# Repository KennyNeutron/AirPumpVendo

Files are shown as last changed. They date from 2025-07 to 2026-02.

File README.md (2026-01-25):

# Coin-Operated Smart Tire Air Pump Vending Machine

## Description

The Coin-Operated Smart Tire Air Pump Vending Machine is a microcontroller-driven, self-service system that provides a fast, safe, and user-friendly way to inflate vehicle tires. Perfect for public locations like vulcanizing shops, parking lots, terminals, and gas stations, it offers tire code lookup, a free DOT safety check, and auto-stop inflation at a target PSI.

## Services

1. **Tire Code Info & Inflation**
   - **Lookup by Code**: Input tire code (e.g., 225/60R16) to get recommended PSI from the internal database.
   - **Manual Input**: Manually set a custom target PSI if the recommended pressure is already known.
   - **Inflation**: Automatic stop at the target PSI with live pressure monitoring.
2. **DOT Code Safety Check (Free Service)**
   - Input DOT code (e.g., 1021) to determine tire age.
   - Displays whether the tire is Safe, requires Caution, or needs Immediate Replacement.

## System Architecture

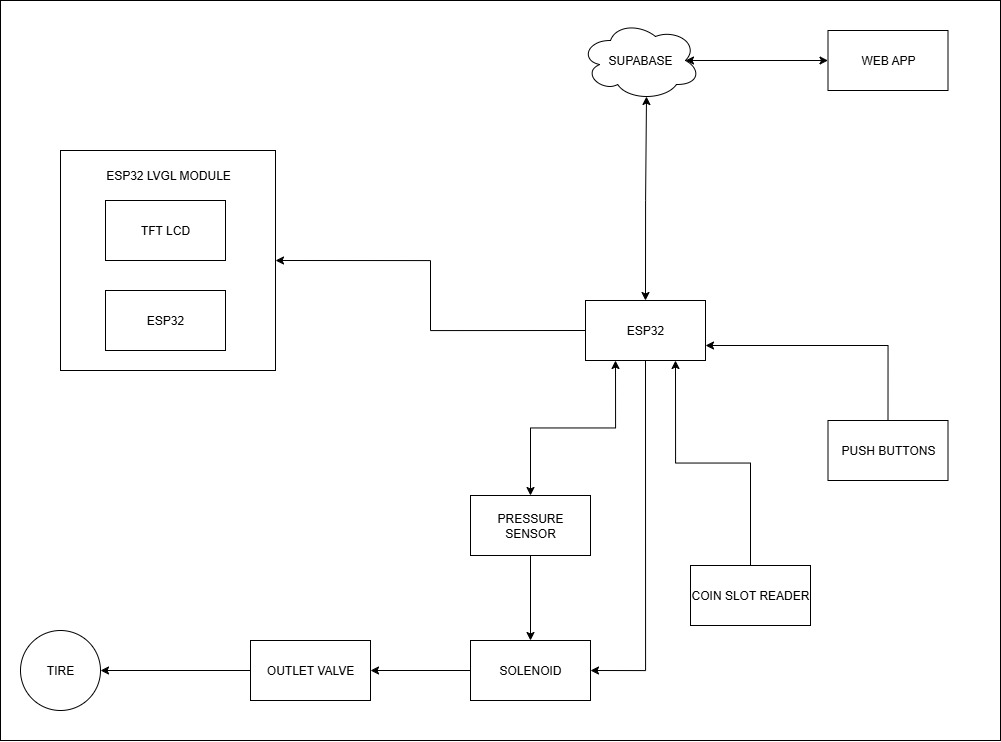
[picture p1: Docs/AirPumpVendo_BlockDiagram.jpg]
Block Diagram


## Hardware Requirements

- Microcontroller (e.g., Arduino Uno or similar)
- TFT display module (7" 800×480 optimized)
- Pressure sensor for live PSI monitoring
- Coin acceptor mechanism (Pulse-based)
- Solid State Relay (SSR) for compressor control
- Power supply and industrial-grade enclosure

## Software Requirements

- **Electron & Next.js**: Modern touch-optimized UI for the operator interface.
- **Arduino Firmware**: C++ logic for sensors, relays, and serial communication.
- **Serial Communication**: Robust protocol between the UI and the controller.

## Installation & Setup

1. **Clone the repository**
   ```bash
   git clone https://github.com/yourusername/smart-tire-air-pump.git
   cd smart-tire-air-pump
   ```
2. **Desktop UI Setup** (Inside `Code/Desktop/AirPumpVendo`)
   ```bash
   npm install
   npm run dev
   ```
3. **Firmware Setup** (Inside `Code/Arduino/AirPumpVendo_Device`)
   - Open `AirPumpVendo_Device.ino` in Arduino IDE.
   - Configure pin definitions and upload to your microcontroller.

## Usage

1. **Select Service**: Choose from the main menu (Tire Service or DOT Check).
2. **Setup Inflation**:
   - For Tire Service: Enter your tire code for a recommendation OR enter PSI manually.
   - For DOT Check: This service is free; follow prompts to check tire safety.
3. **Payment**: Insert coins as required for paid services. The single total cost is displayed on screen.
4. **Inflation**:
   - Connect the hose to the tire valve.
   - Press “Start Inflation.”
   - The machine auto-stops once the target PSI is reached.
5. **Completion**: Remove the hose and return to the home screen.

## Admin Control Panel

- Secure access via password-protected login.
- **Manage Tire Codes**: Add/remove recommended PSI mappings.
- **DOT Database**: Update the list of known DOT codes and safety thresholds.
- **Pricing Management**: Set standard rates for info and inflation services.
- **Analytics**: View weekly revenue reports and service usage statistics.

## Contributing

1. Fork the repository.
2. Create a new branch (`git checkout -b feature/YourFeature`).
3. Commit your changes (`git commit -m "Add YourFeature"`).
4. Push to branch (`git push origin feature/YourFeature`).
5. Open a Pull Request.

## License

This project is licensed under the MIT License. See [LICENSE](LICENSE) for details.

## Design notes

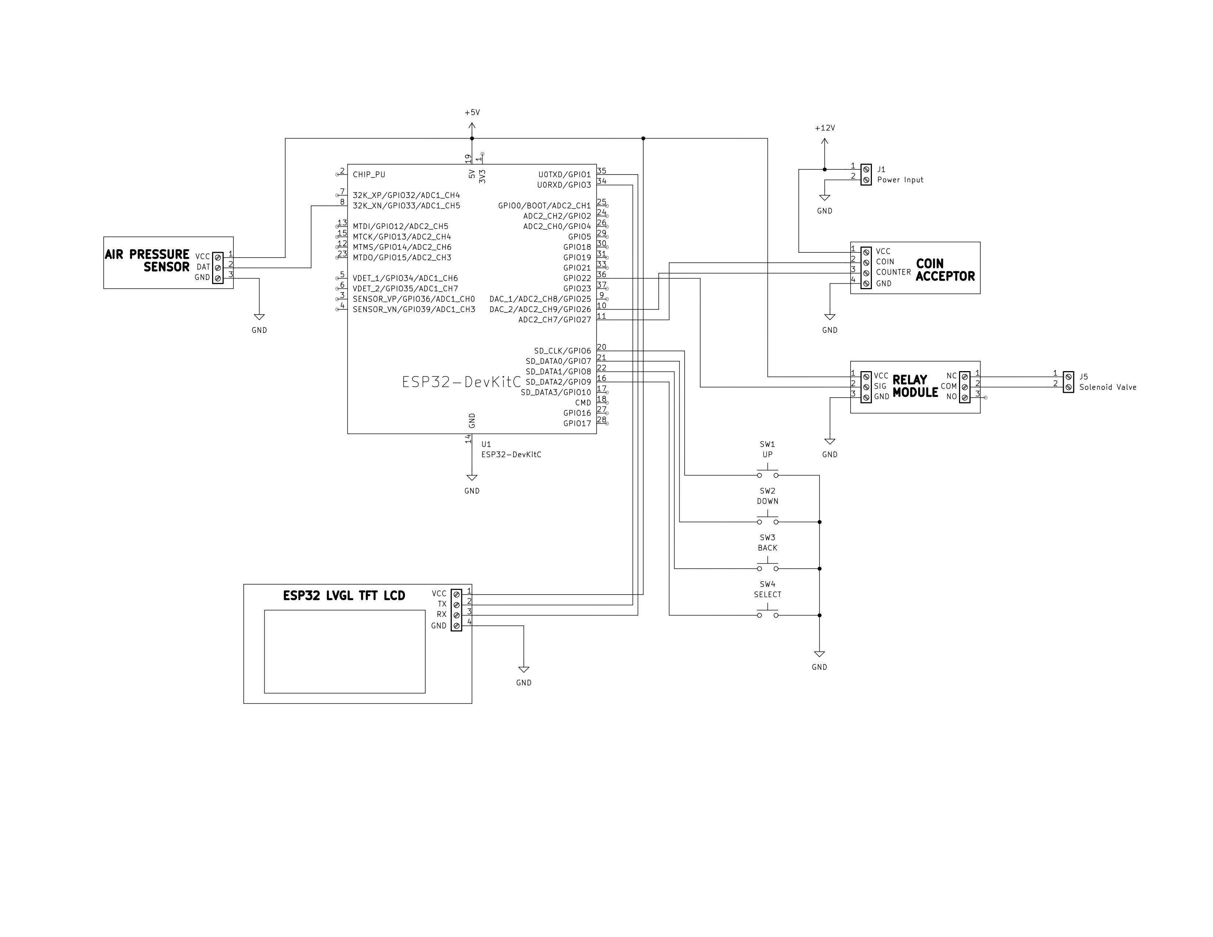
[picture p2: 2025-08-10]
Docs/AirPumpVendo_FullSchematic.jpg

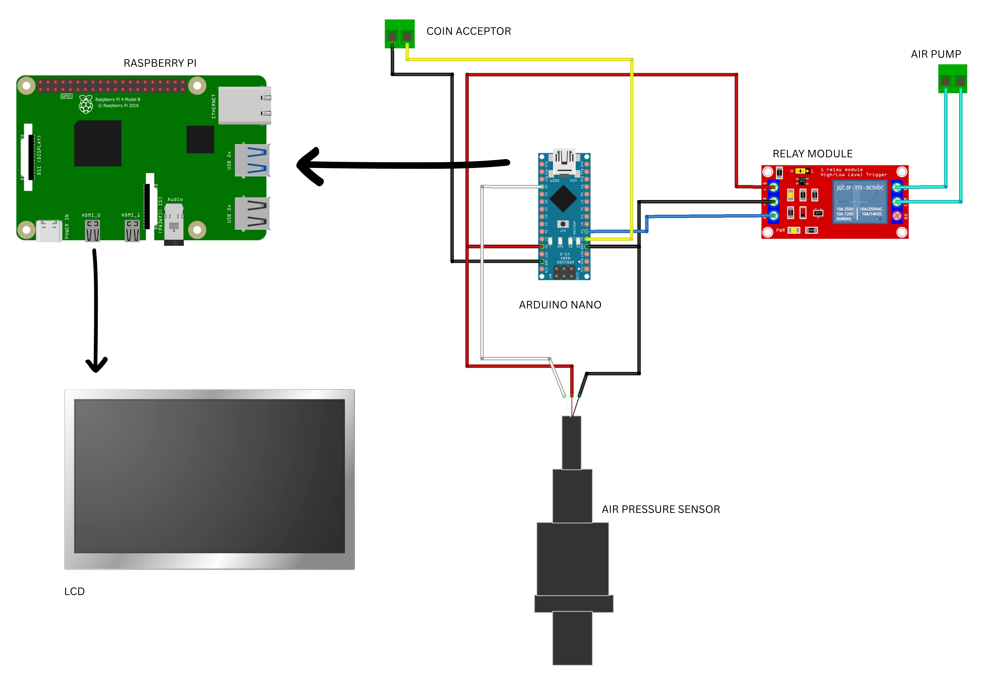
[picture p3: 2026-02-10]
Docs/VendoAirPump_V2.jpg

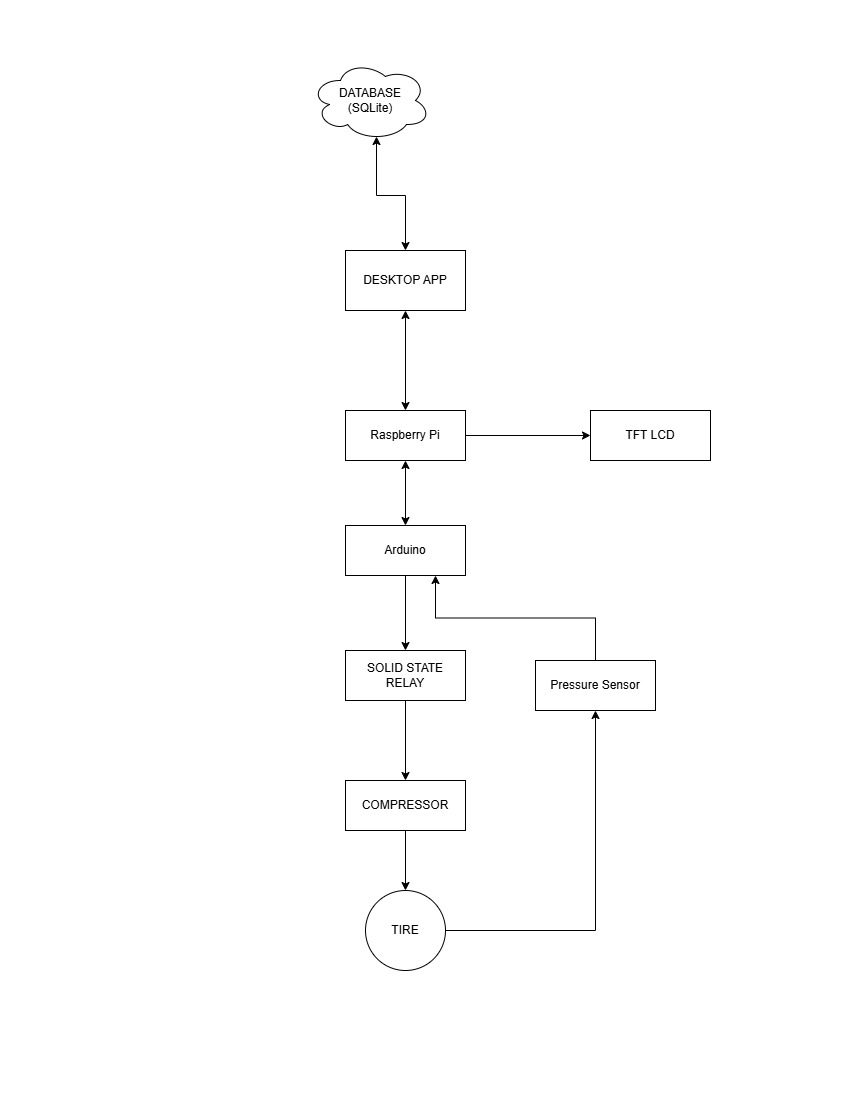
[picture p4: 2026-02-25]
Docs/UpdatedBlockDiagram2026.jpg

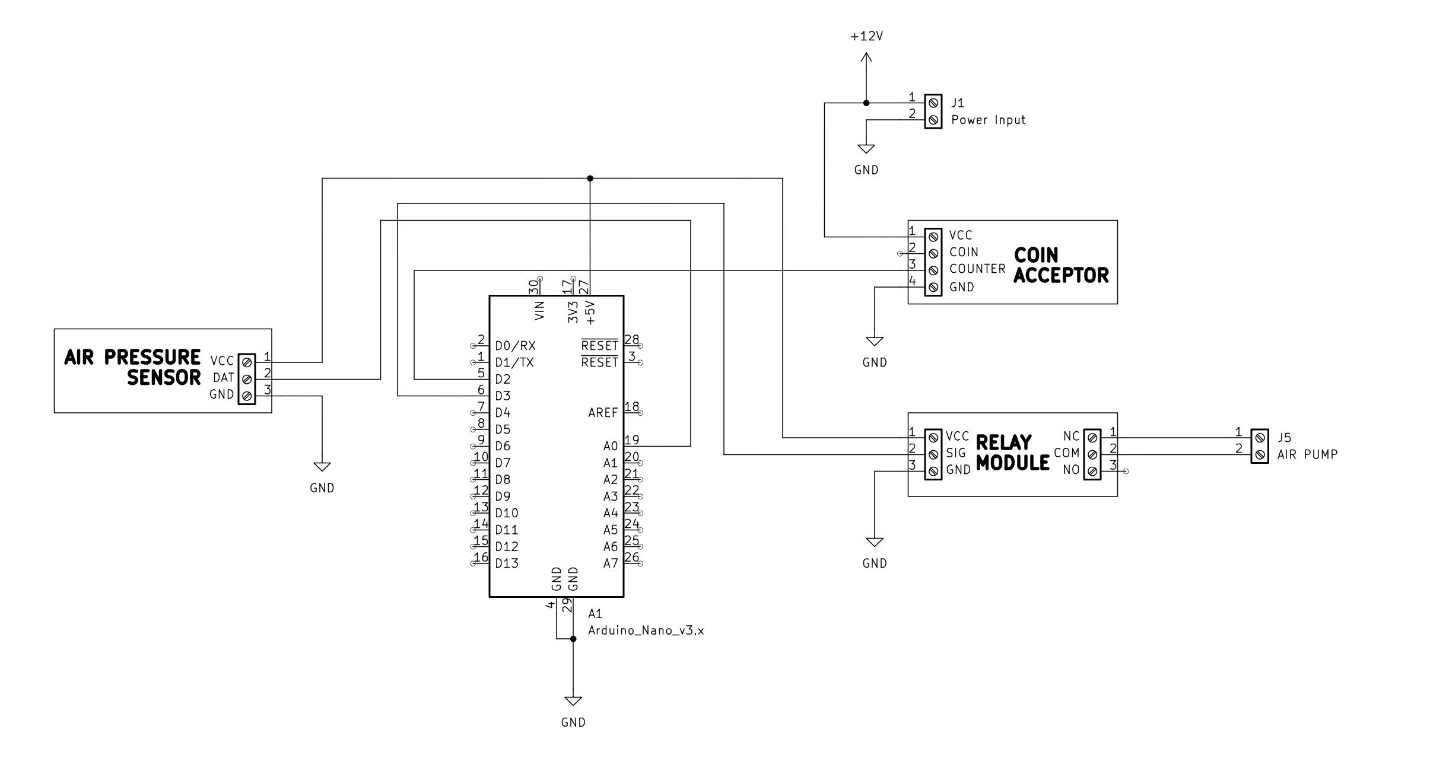
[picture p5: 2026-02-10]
Docs/AirPumpVendo_SCH_V2.jpg

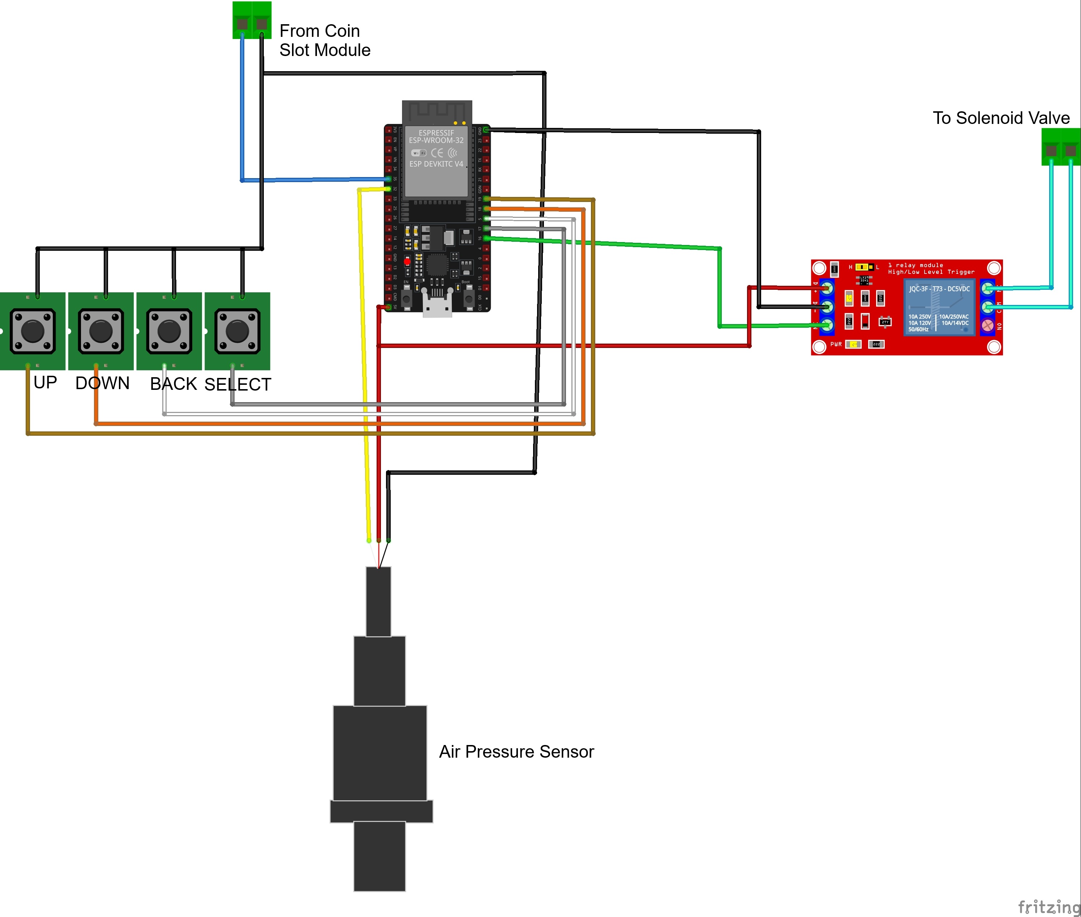
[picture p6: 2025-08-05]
Docs/VendoAirPump_bb.jpg

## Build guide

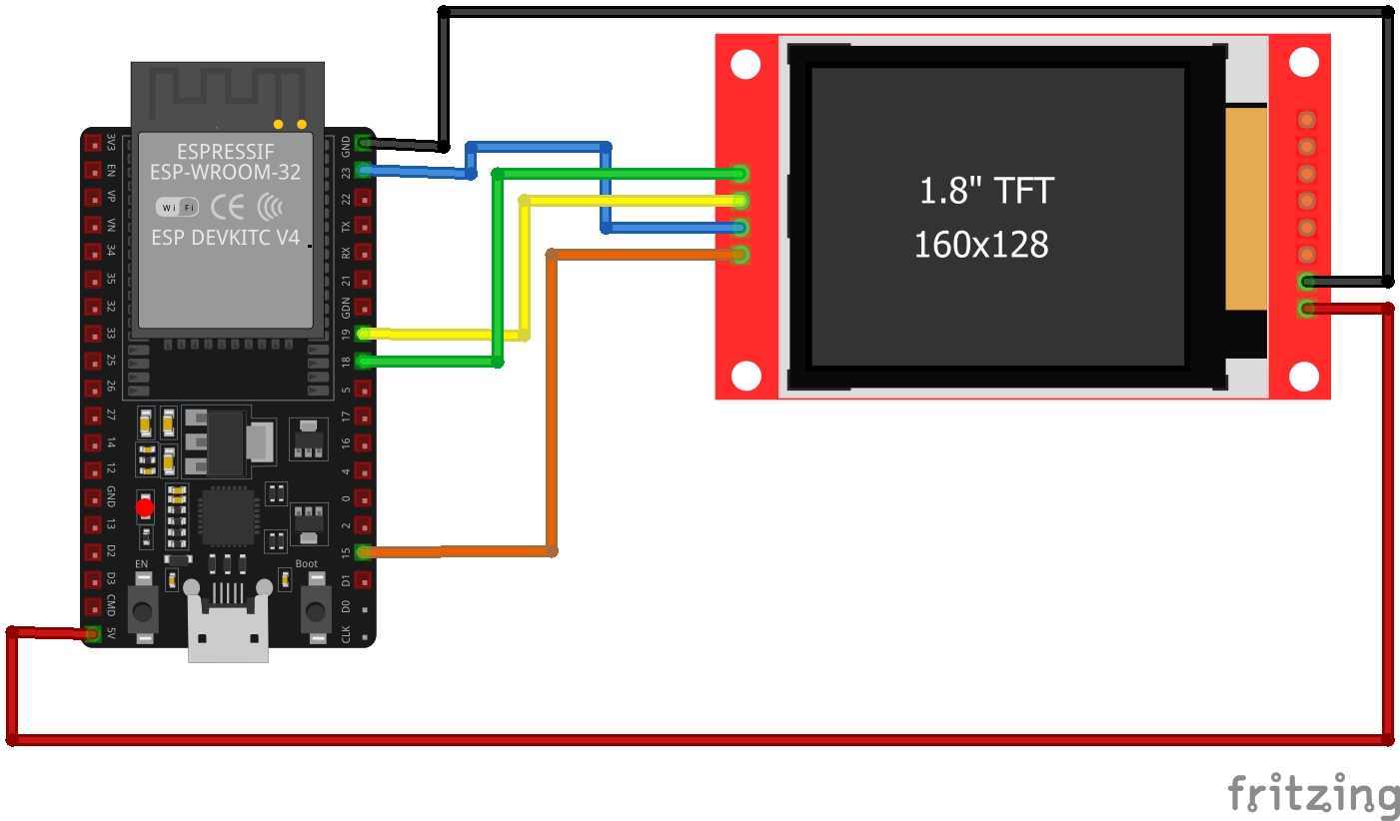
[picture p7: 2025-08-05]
Docs/ESP32_TFT_Module_Wiring.jpg

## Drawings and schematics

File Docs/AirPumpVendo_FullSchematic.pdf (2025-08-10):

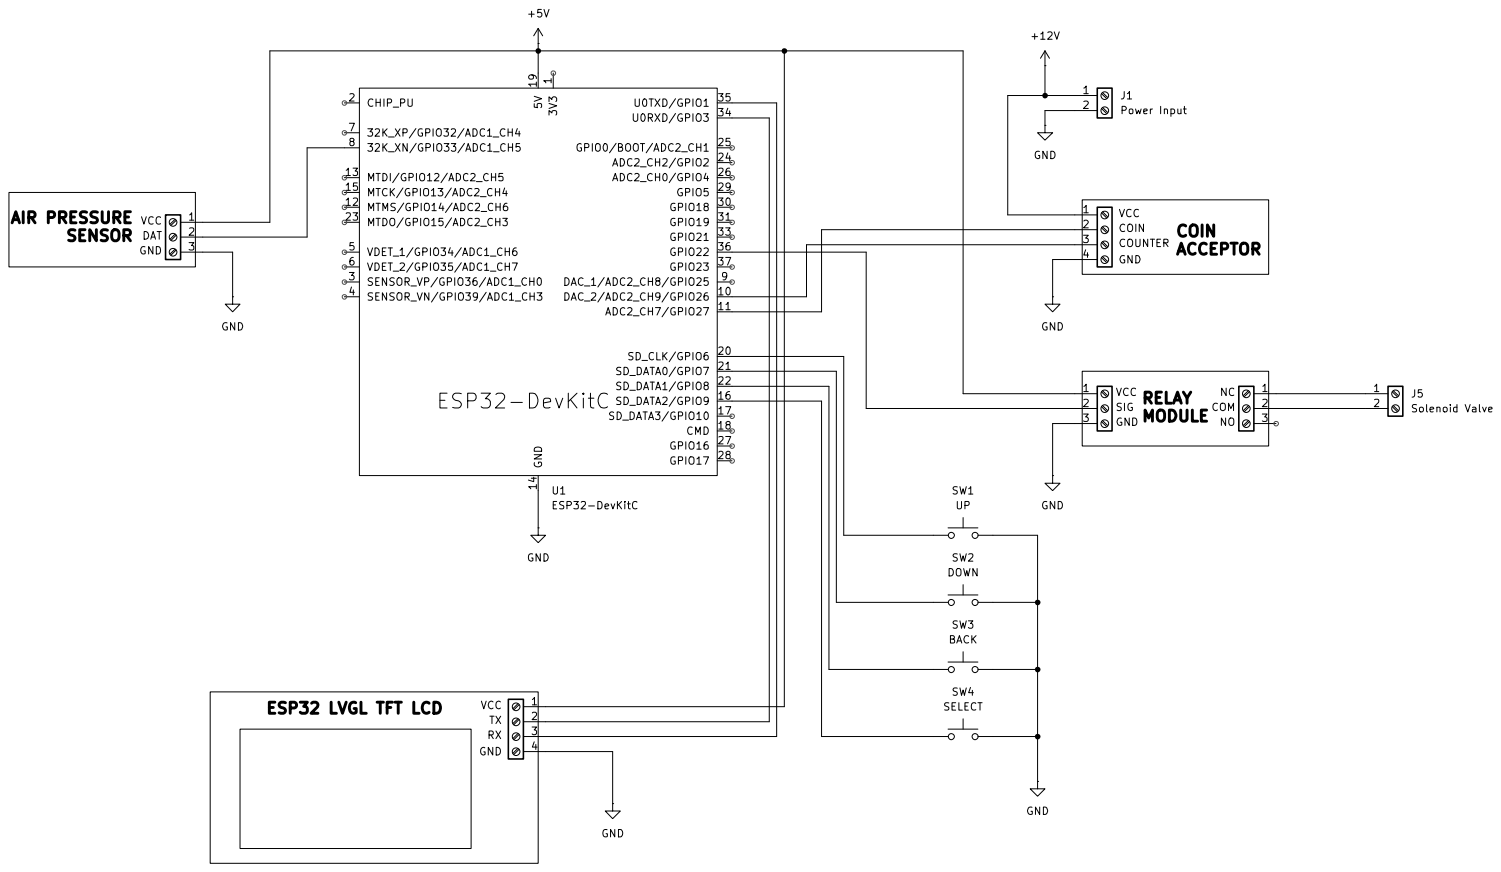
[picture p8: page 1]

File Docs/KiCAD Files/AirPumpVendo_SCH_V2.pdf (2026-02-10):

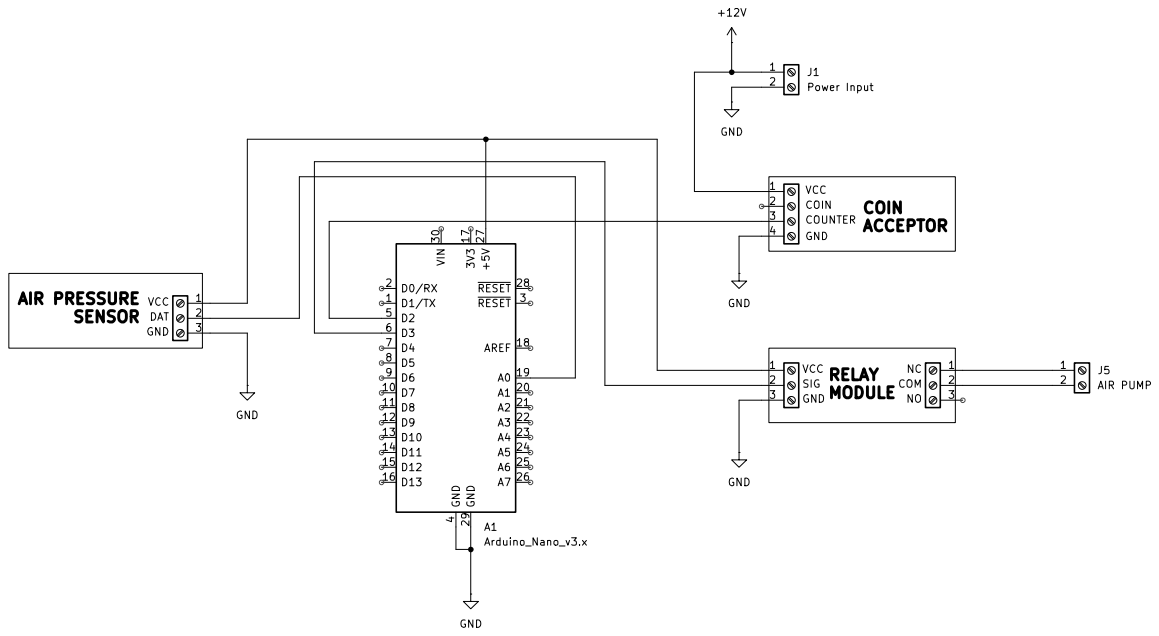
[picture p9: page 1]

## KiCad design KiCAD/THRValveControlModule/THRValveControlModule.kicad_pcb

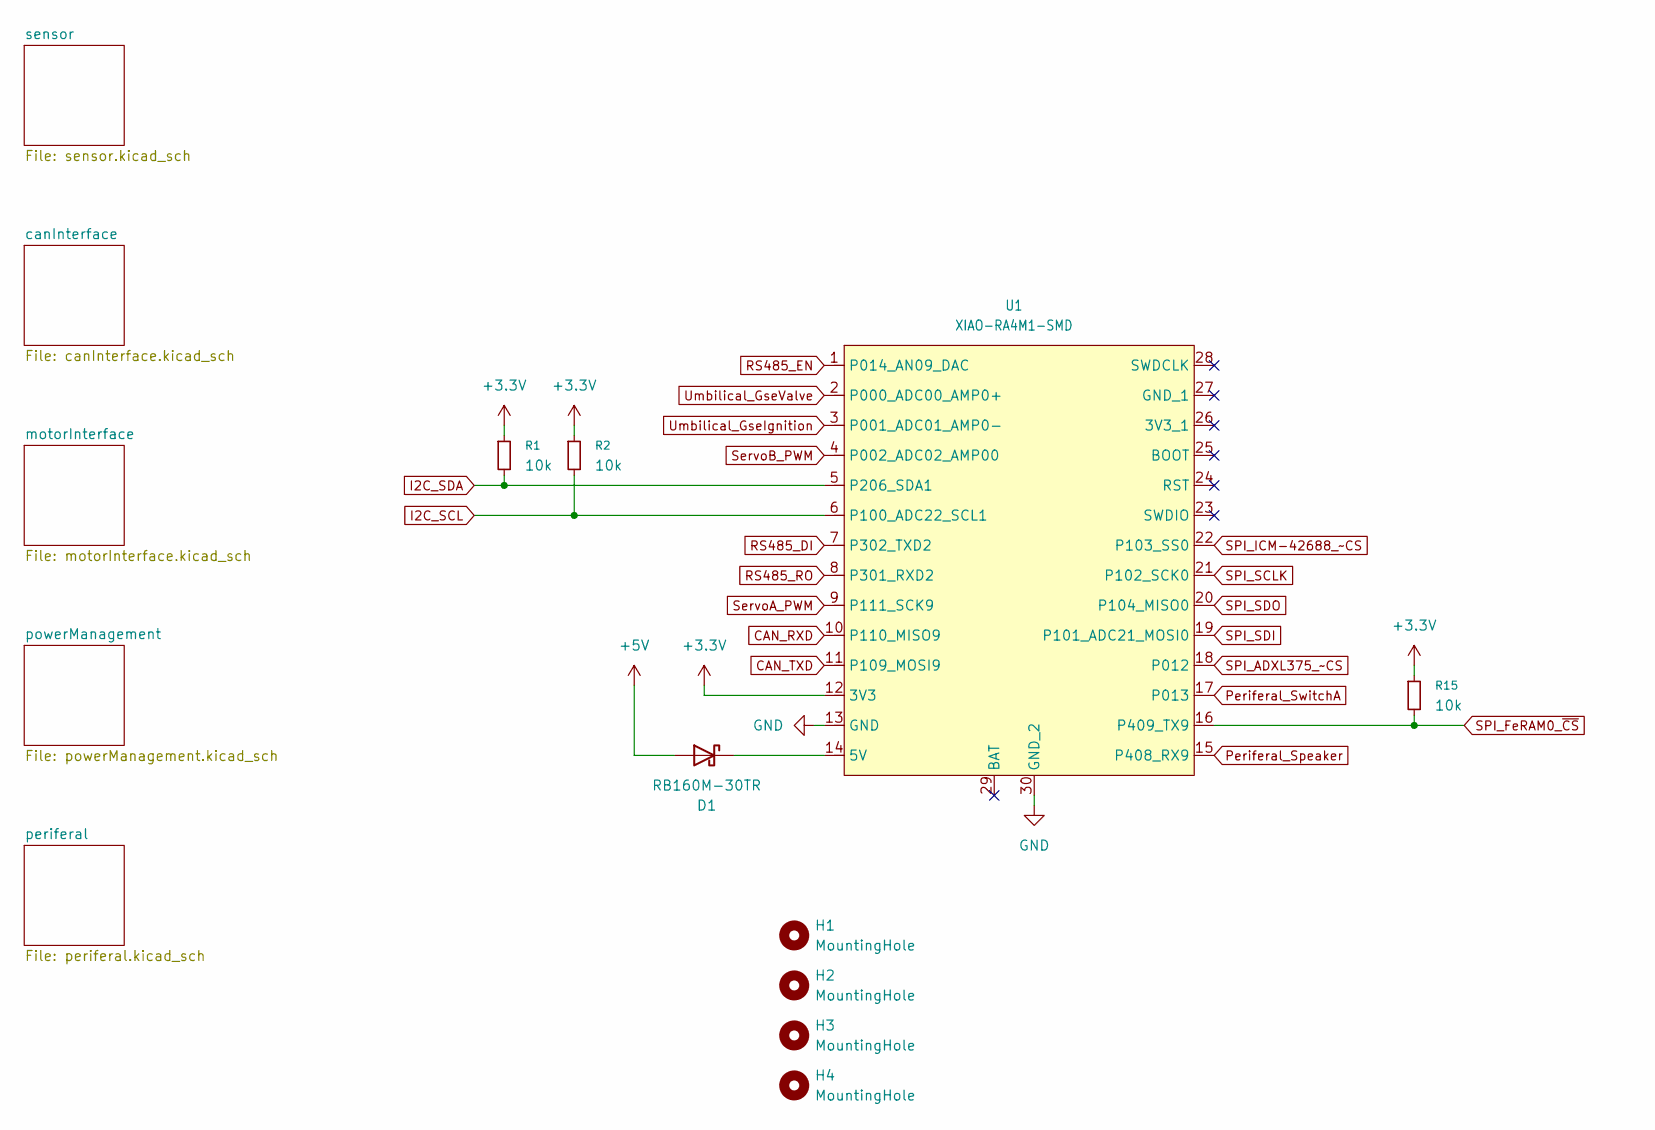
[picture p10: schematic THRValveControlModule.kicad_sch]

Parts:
D1: RB160M-30TR; D_SOD-123
H1, H2, H3, H4: MountingHole; MountingHole_3.2mm_M3_Pad_Via
R1, R2, R15: 10k; R_0603_1608Metric_Pad0.98x0.95mm_HandSolder
U1: XIAO-RA4M1-SMD

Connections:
+3.3V: R1.1, R2.1, R15.1, U1.12 (3V3); also elsewhere on the board
+5V: D1.2 (A); also elsewhere on the board
CAN_RXD: U1.10 (P110_MISO9); also elsewhere on the board
CAN_TXD: U1.11 (P109_MOSI9); also elsewhere on the board
GND: U1.13 (GND), U1.30 (GND_2); also elsewhere on the board
I2C_SCL: R2.2, U1.6 (P100_ADC22_SCL1); also elsewhere on the board
I2C_SDA: R1.2, U1.5 (P206_SDA1); also elsewhere on the board
unnamed: D1.1 (K), U1.14 (5V)
Periferal_Speaker: U1.15 (P408_RX9); also elsewhere on the board
Periferal_SwitchA: U1.17 (P013); also elsewhere on the board
RS485_DI: U1.7 (P302_TXD2); also elsewhere on the board
RS485_EN: U1.1 (P014_AN09_DAC); also elsewhere on the board
RS485_RO: U1.8 (P301_RXD2); also elsewhere on the board
SPI_ADXL375_~CS: U1.18 (P012); also elsewhere on the board
SPI_FeRAM0_~CS: R15.2, U1.16 (P409_TX9); also elsewhere on the board
SPI_ICM-42688_~CS: U1.22 (P103_SS0); also elsewhere on the board
SPI_SCLK: U1.21 (P102_SCK0); also elsewhere on the board
SPI_SDI: U1.19 (P101_ADC21_MOSI0); also elsewhere on the board
SPI_SDO: U1.20 (P104_MISO0); also elsewhere on the board
ServoA_PWM: U1.9 (P111_SCK9); also elsewhere on the board
ServoB_PWM: U1.4 (P002_ADC02_AMP00); also elsewhere on the board
Umbilical_GseIgnition: U1.3 (P001_ADC01_AMP0-); also elsewhere on the board
Umbilical_GseValve: U1.2 (P000_ADC00_AMP0+); also elsewhere on the board

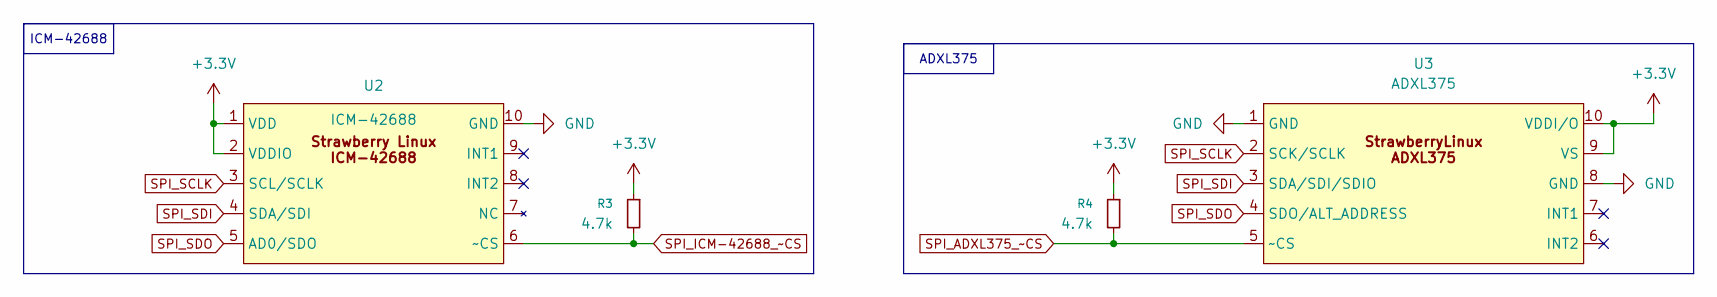
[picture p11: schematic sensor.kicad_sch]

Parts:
R3, R4: 4.7k; R_0603_1608Metric_Pad0.98x0.95mm_HandSolder
U2: ICM-42688; StrawberryLinux_ICM-42688-P
U3: ADXL375; StrawberryLinux_ADXL375

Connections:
+3.3V: R3.1, R4.1, U2.1 (VDD), U2.2 (VDDIO), U3.9 (VS), U3.10 (VDDI/O); also elsewhere on the board
GND: U2.10 (GND), U3.1 (GND), U3.8 (GND); also elsewhere on the board
SPI_ADXL375_~CS: R4.2, U3.5 (~CS); also elsewhere on the board
SPI_ICM-42688_~CS: R3.2, U2.6 (~CS); also elsewhere on the board
SPI_SCLK: U2.3 (SCL/SCLK), U3.2 (SCK/SCLK); also elsewhere on the board
SPI_SDI: U2.4 (SDA/SDI), U3.3 (SDA/SDI/SDIO); also elsewhere on the board
SPI_SDO: U2.5 (AD0/SDO), U3.4 (SDO/ALT_ADDRESS); also elsewhere on the board

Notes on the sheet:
ICM-42688
ADXL375

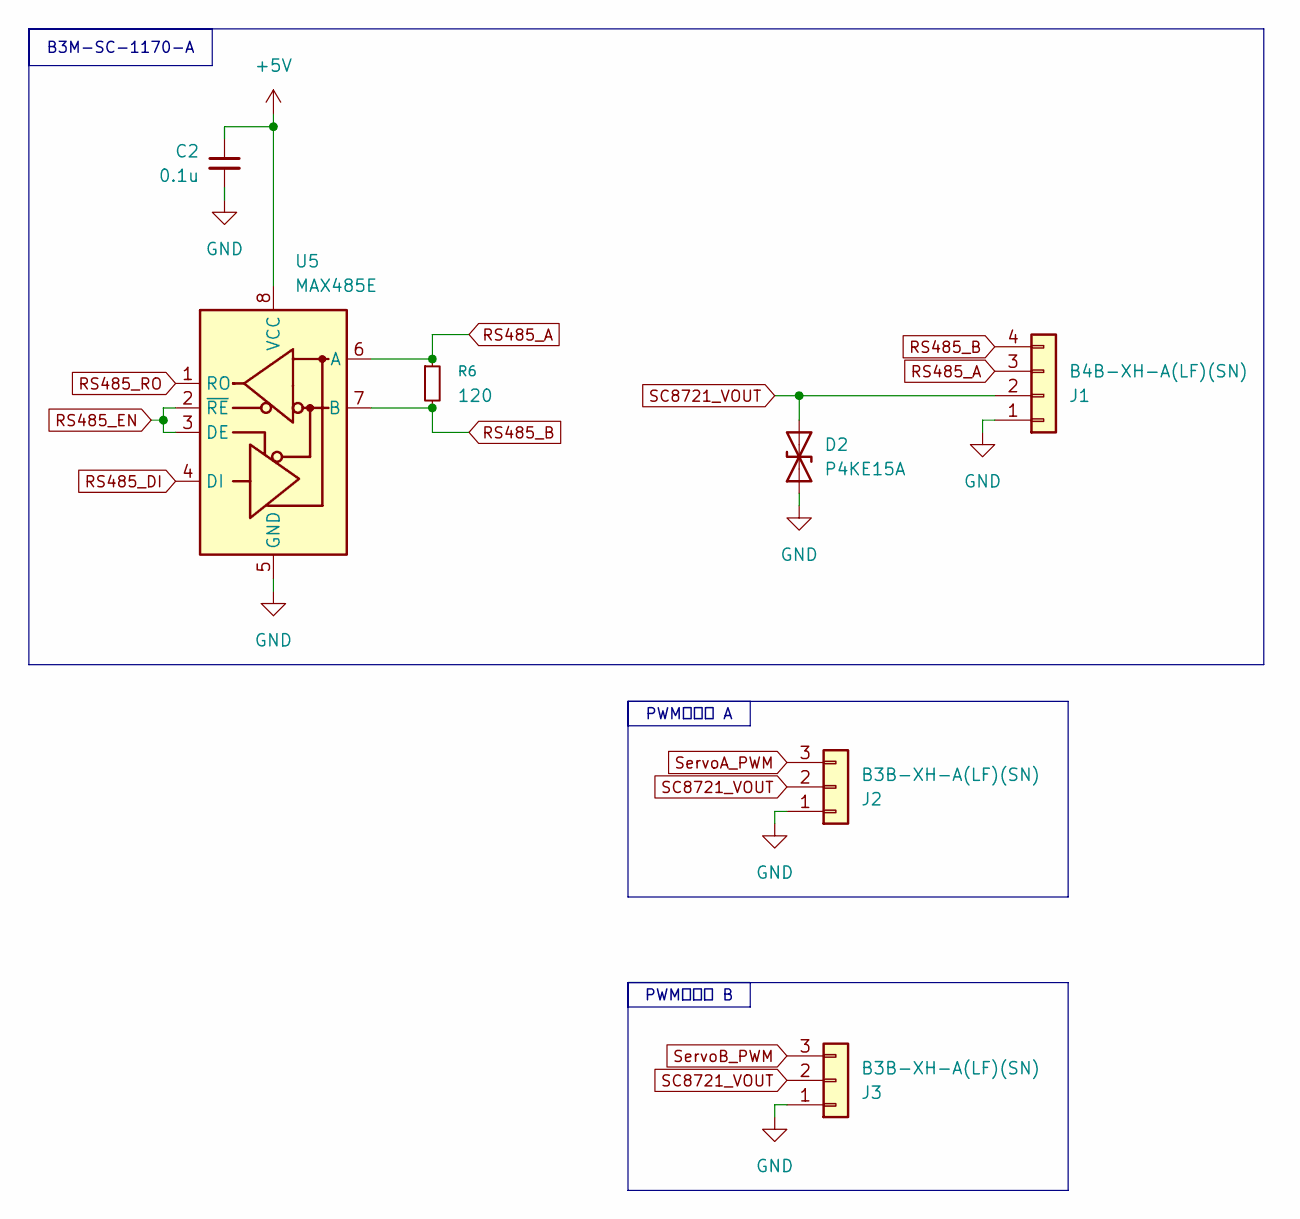
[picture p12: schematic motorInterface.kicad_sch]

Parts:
C2: 0.1u; C_0603_1608Metric_Pad1.08x0.95mm_HandSolder
D2: P4KE15A; D_DO-41_SOD81_P2.54mm_Vertical_KathodeUp
J1: B4B-XH-A(LF)(SN); JST_XH_B4B-XH-A_1x04_P2.50mm_Vertical
J2, J3: B3B-XH-A(LF)(SN); JST_XH_B3B-XH-A_1x03_P2.50mm_Vertical
R6: 120; R_0603_1608Metric_Pad0.98x0.95mm_HandSolder
U5: MAX485E; SOIC-8_3.9x4.9mm_P1.27mm

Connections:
+5V: C2.1, U5.8 (VCC); also elsewhere on the board
GND: C2.2, D2.1 (A1), J1.1, J2.1, J3.1, U5.5 (GND); also elsewhere on the board
RS485_A: J1.3, R6.1, U5.6 (A)
RS485_B: J1.4, R6.2, U5.7 (B)
RS485_DI: U5.4 (DI); also elsewhere on the board
RS485_EN: U5.2 (~RE), U5.3 (DE); also elsewhere on the board
RS485_RO: U5.1 (RO); also elsewhere on the board
SC8721_VOUT: D2.2 (A2), J1.2, J2.2, J3.2; also elsewhere on the board
ServoA_PWM: J2.3; also elsewhere on the board
ServoB_PWM: J3.3; also elsewhere on the board

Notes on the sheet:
PWMサーボ A
PWMサーボ B
B3M-SC-1170-A

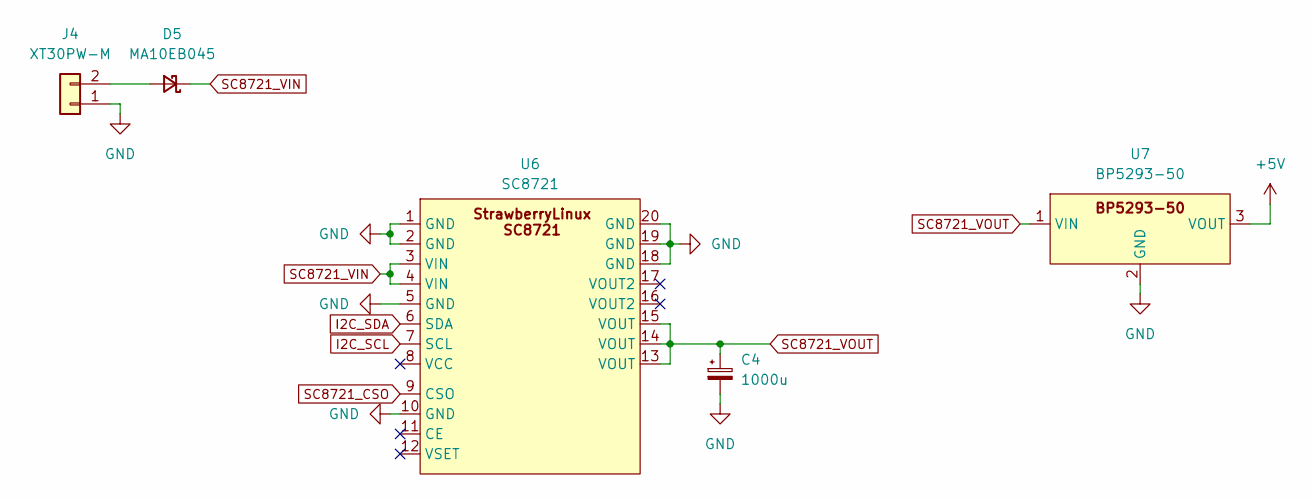
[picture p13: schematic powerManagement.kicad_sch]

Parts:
C4: 1000u; CP_Radial_D12.5mm_P5.00mm
D5: MA10EB045; MA_DO-221BC
J4: XT30PW-M; AMASS_XT30PW-M_1x02_P2.50mm_Horizontal
U6: SC8721; StrawberryLinux_SC8721
U7: BP5293-50

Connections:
+5V: U7.3 (VOUT); also elsewhere on the board
GND: C4.2, J4.1, U6.1 (GND), U6.2 (GND), U6.5 (GND), U6.10 (GND), U6.18 (GND), U6.19 (GND), U6.20 (GND), U7.2 (GND); also elsewhere on the board
I2C_SCL: U6.7 (SCL); also elsewhere on the board
I2C_SDA: U6.6 (SDA); also elsewhere on the board
unnamed: D5.2 (A), J4.2
SC8721_CSO: U6.9 (CSO)
SC8721_VIN: D5.1 (K), U6.3 (VIN), U6.4 (VIN)
SC8721_VOUT: C4.1, U6.13 (VOUT), U6.14 (VOUT), U6.15 (VOUT), U7.1 (VIN); also elsewhere on the board

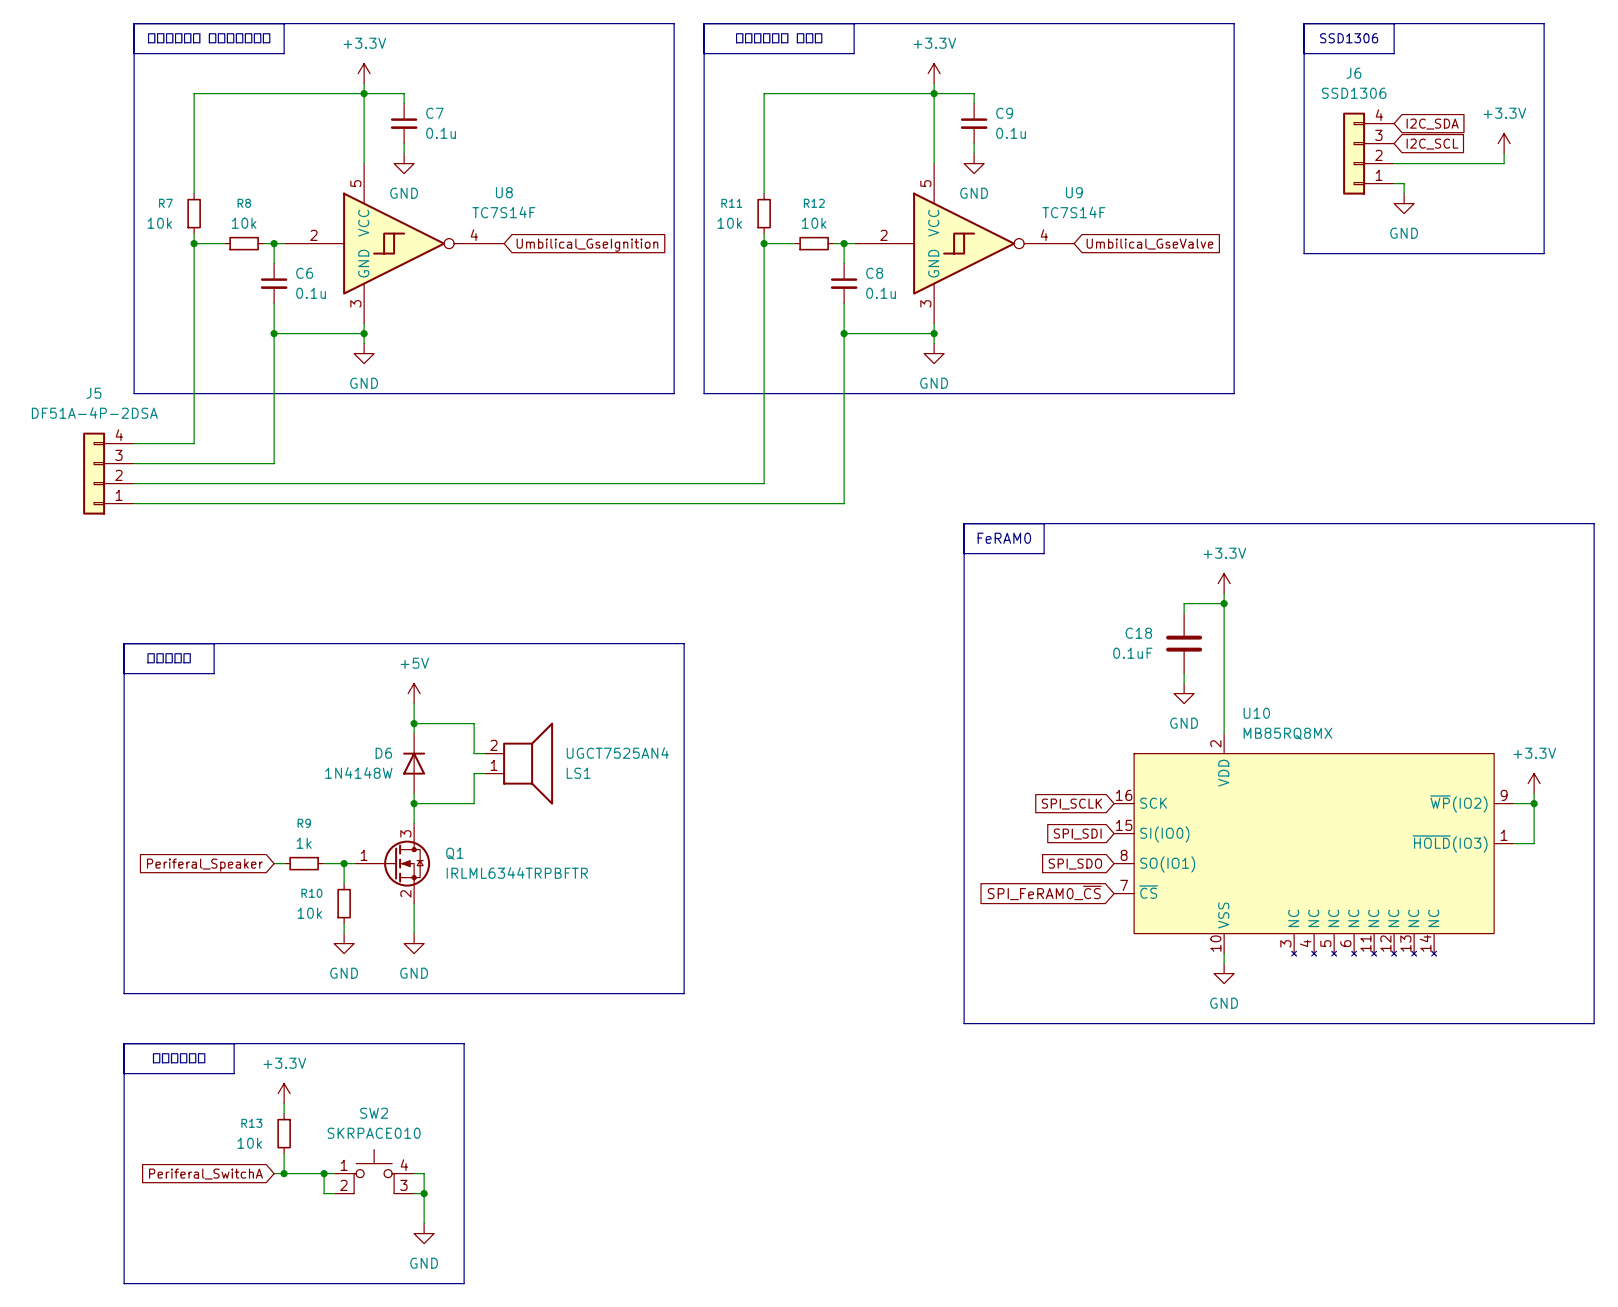
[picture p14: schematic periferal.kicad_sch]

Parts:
C6, C7, C8, C9: 0.1u; C_0603_1608Metric_Pad1.08x0.95mm_HandSolder
C18: 0.1uF; C_0603_1608Metric_Pad1.08x0.95mm_HandSolder
D6: 1N4148W; D_SOD-123
J5: DF51A-4P-2DSA
J6: SSD1306; PinHeader_1x04_P2.54mm_Vertical
LS1: UGCT7525AN4
Q1: IRLML6344TRPBFTR; SOT-23_Handsoldering
R7, R8, R10, R11, R12, R13: 10k; R_0603_1608Metric_Pad0.98x0.95mm_HandSolder
R9: 1k; R_0603_1608Metric_Pad0.98x0.95mm_HandSolder
SW2: SKRPACE010
U8, U9: TC7S14F; SOT-23-5
U10: MB85RQ8MX; SOIC-16W_7.5x10.3mm_P1.27mm

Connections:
+3.3V: C7.1, C9.1, C18.1, J6.2, R7.2, R11.2, R13.1, U8.5 (VCC), U9.5 (VCC), U10.1 (~HOLD(IO3)), U10.2 (VDD), U10.9 (~WP(IO2)); also elsewhere on the board
+5V: D6.1 (K), LS1.2; also elsewhere on the board
GND: C6.2, C7.2, C8.2, C9.2, C18.2, J5.1, J5.3, J6.1, Q1.2 (S), R10.1, SW2.3 (K), SW2.4 (A), U8.3 (GND), U9.3 (GND), U10.10 (VSS); also elsewhere on the board
I2C_SCL: J6.3; also elsewhere on the board
I2C_SDA: J6.4; also elsewhere on the board
unnamed: C6.1, R8.2, U8.2
unnamed: C8.1, R12.2, U9.2
unnamed: D6.2 (A), LS1.1, Q1.3 (D)
unnamed: J5.2, R11.1, R12.1
unnamed: J5.4, R7.1, R8.1
unnamed: Q1.1 (G), R9.1, R10.2
Periferal_Speaker: R9.2; also elsewhere on the board
Periferal_SwitchA: R13.2, SW2.1, SW2.2; also elsewhere on the board
SPI_FeRAM0_~CS: U10.7 (~CS); also elsewhere on the board
SPI_SCLK: U10.16 (SCK); also elsewhere on the board
SPI_SDI: U10.15 (SI(IO0)); also elsewhere on the board
SPI_SDO: U10.8 (SO(IO1)); also elsewhere on the board
Umbilical_GseIgnition: U8.4; also elsewhere on the board
Umbilical_GseValve: U9.4; also elsewhere on the board

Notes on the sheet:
アンビリカル イグニッション
SSD1306
アンビリカル バルブ
FeRAM0
ユーザー入力
スピーカー

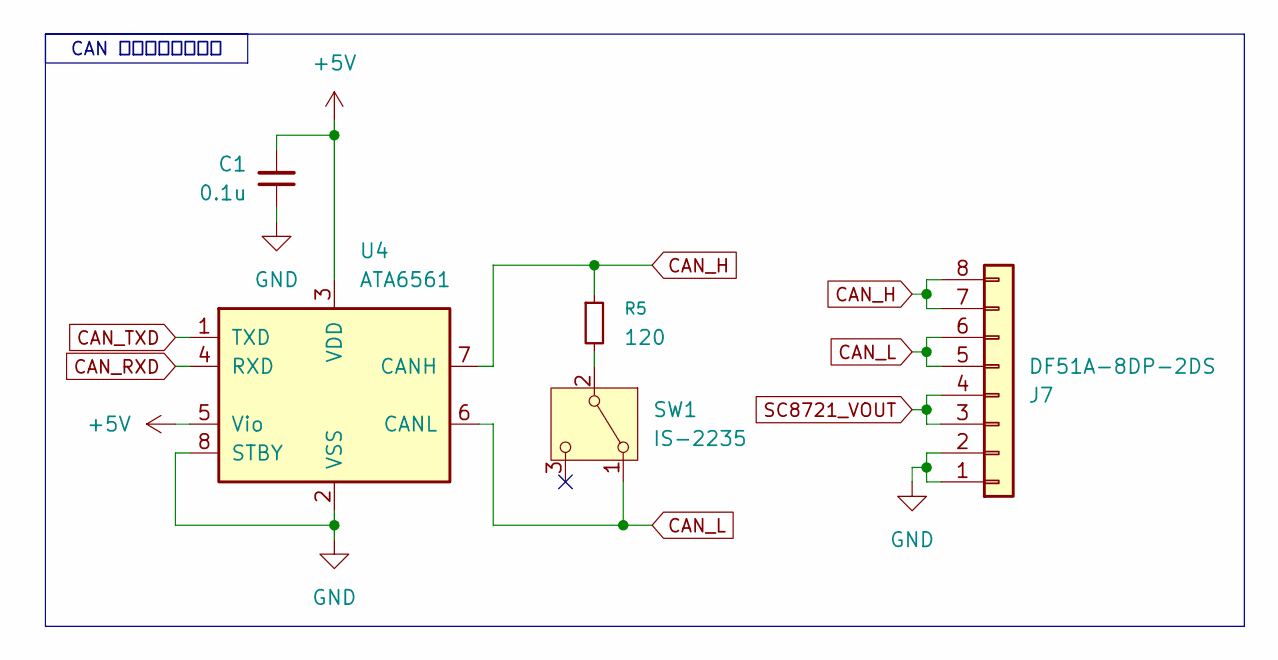
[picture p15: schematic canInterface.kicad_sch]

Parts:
C1: 0.1u; C_0603_1608Metric_Pad1.08x0.95mm_HandSolder
J7: DF51A-8DP-2DS
R5: 120; R_0603_1608Metric_Pad0.98x0.95mm_HandSolder
SW1: IS-2235; SW_CK_JS202011CQN_DPDT_Straight
U4: ATA6561; SOIC-8_3.9x4.9mm_P1.27mm

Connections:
+5V: C1.2, U4.3 (VDD), U4.5 (Vio); also elsewhere on the board
CAN_H: J7.7, J7.8, R5.1, U4.7 (CANH)
CAN_L: J7.5, J7.6, SW1.1 (A), U4.6 (CANL); also elsewhere on the board
CAN_RXD: U4.4 (RXD); also elsewhere on the board
CAN_TXD: U4.1 (TXD); also elsewhere on the board
GND: C1.1, J7.1, J7.2, U4.2 (VSS), U4.8 (STBY); also elsewhere on the board
unnamed 17: R5.2, SW1.2 (B); also elsewhere on the board
SC8721_VOUT: J7.3, J7.4; also elsewhere on the board

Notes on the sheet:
CAN インターフェース

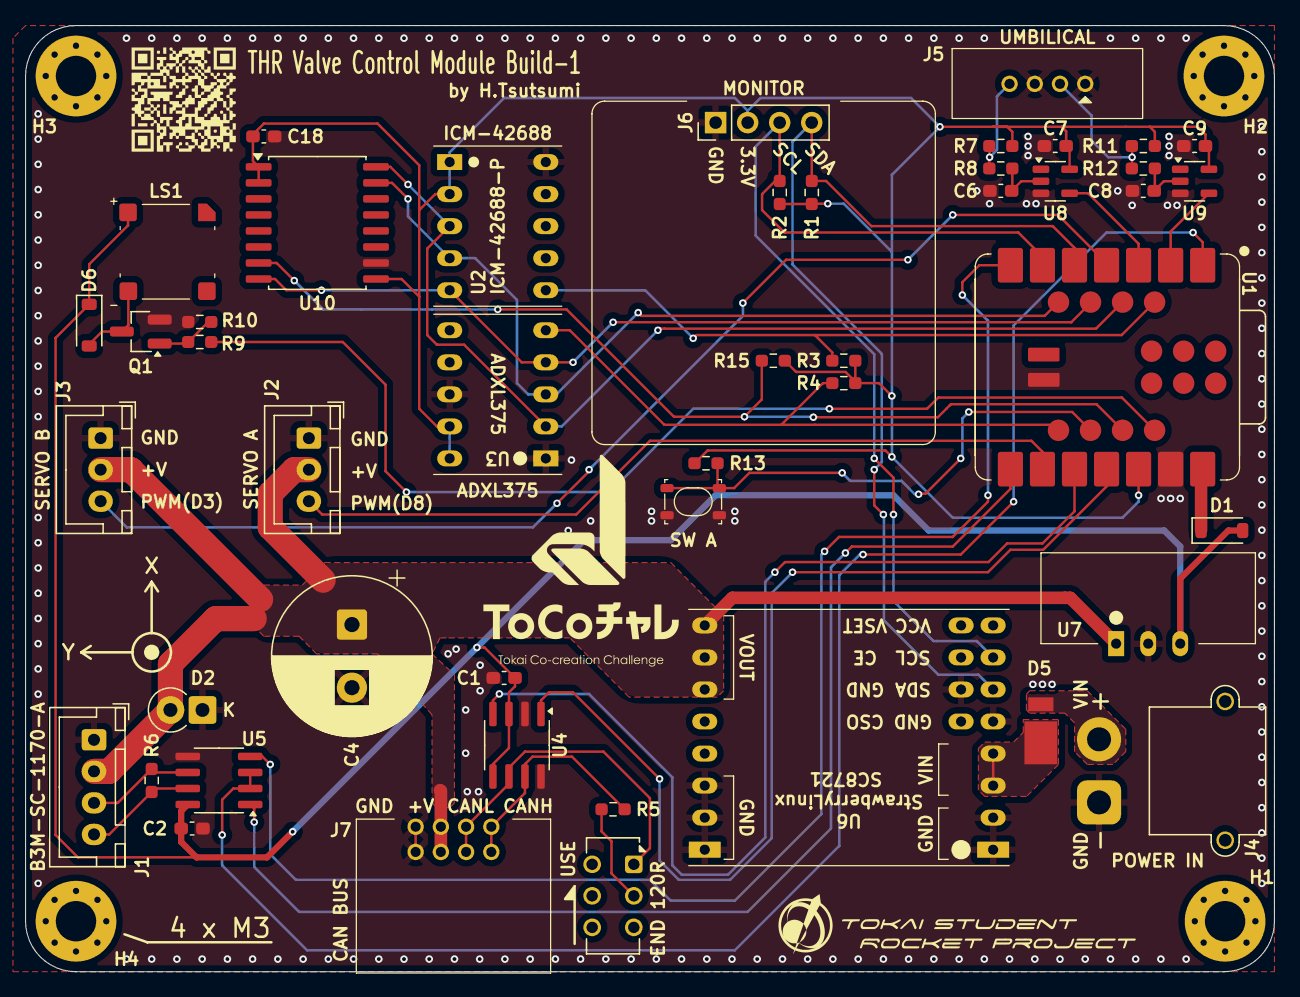
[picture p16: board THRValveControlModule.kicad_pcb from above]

Board: 2 copper layers, 99.0 x 75.0 mm, 51 parts (0 on the bottom side), 37 nets.

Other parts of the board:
END 120R: IS-2235; SW_CK_JS202011CQN_DPDT_Straight
SW A: SKRPACE010

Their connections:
CAN_L: END 120R.1 (A); also elsewhere on the board
GND: SW A.3 (K), SW A.4 (A); also elsewhere on the board
unnamed 17: END 120R.2 (B); also elsewhere on the board
Periferal_SwitchA: SW A.1, SW A.2; also elsewhere on the board

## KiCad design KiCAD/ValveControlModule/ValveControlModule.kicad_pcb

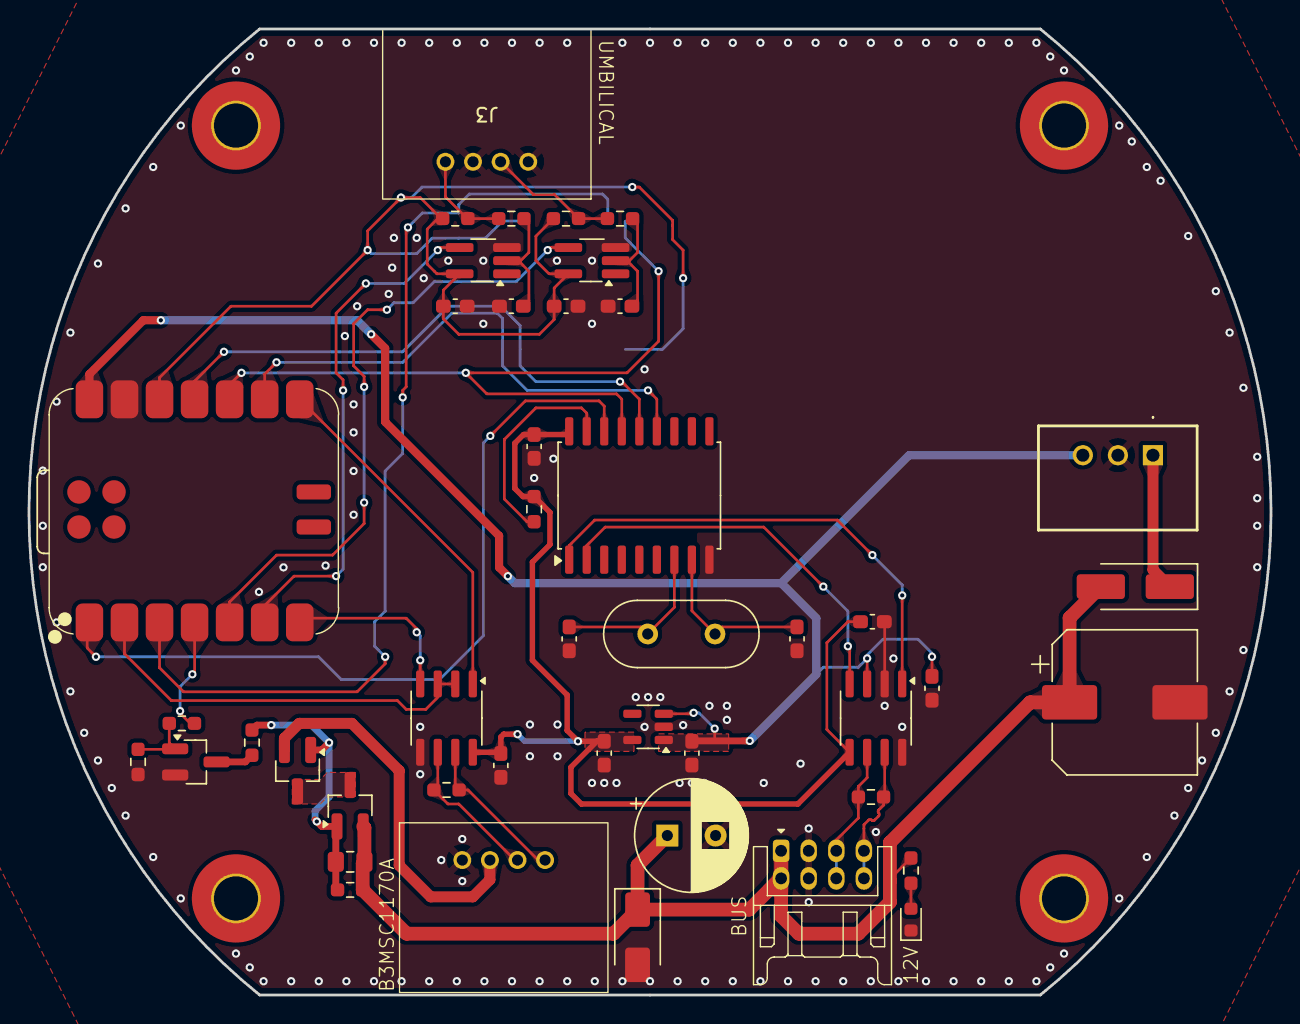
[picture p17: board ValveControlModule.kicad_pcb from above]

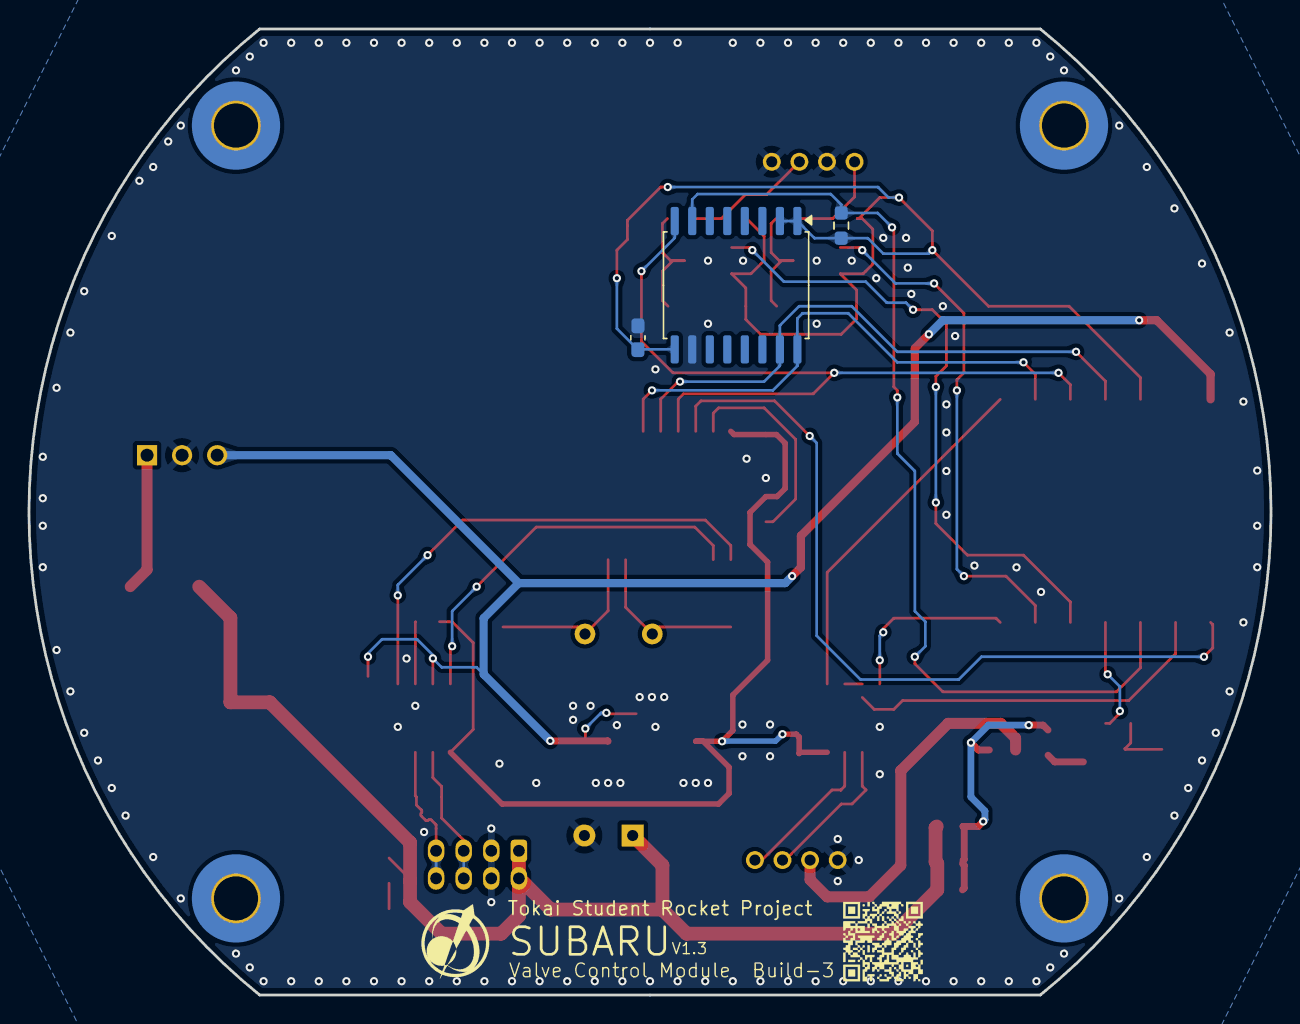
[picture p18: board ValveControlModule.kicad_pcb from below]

Board: 2 copper layers, 90.0 x 70.0 mm, 52 parts (3 on the bottom side), 36 nets.

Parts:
C1, C3, C4, C5, C11, C12, C13, C14, C18: 0.1uF; C_0603_1608Metric_Pad1.08x0.95mm_HandSolder
C6, C7: 15pF; C_0603_1608Metric_Pad1.08x0.95mm_HandSolder
C9, C10: 1uF; C_0603_1608Metric_Pad1.08x0.95mm_HandSolder
C15: 330uF; CP_Elec_10x10
C16: 100uF; CP_Radial_D8.0mm_P3.50mm
C17: 22uF; C_0805_2012Metric_Pad1.18x1.45mm_HandSolder
D1: SMAJ45A; D_SMA
D3: Green; LED_0603_1608Metric
D9: SB34AFC; D_SMA_Handsoldering
H1, H2, H3, H4: MountingHole_Pad; MountingHole_3.2mm_M3_Pad_TopBottom
J1, J3: DF51A-4P-2DS
J2: DF11-8DP-2DS
PS1: M78AR05-0.5; M78AR03305
Q2, Q4: AO3401A; SOT-23_Handsoldering
Q3: AO3400A; SOT-23_Handsoldering
R1, R6: 120; R_0603_1608Metric_Pad0.98x0.95mm_HandSolder
R4: 10K; R_0603_1608Metric_Pad0.98x0.95mm_HandSolder
R9: 4.7k; R_0603_1608Metric_Pad0.98x0.95mm_HandSolder
R10: 820R; R_0603_1608Metric_Pad0.98x0.95mm_HandSolder
R11: 2.4kR; R_0603_1608Metric_Pad0.98x0.95mm_HandSolder
R12, R14, R24, R25, R26, R27: 10kR; R_0603_1608Metric_Pad0.98x0.95mm_HandSolder
R13: 100kR; R_0603_1608Metric_Pad0.98x0.95mm_HandSolder
U1: XIAO-RP2040-DIP; XIAO-RP2040-SMD
U2: LT1785xS8; SOIC-8_3.9x4.9mm_P1.27mm
U3: MCP2515-xSO; SOIC-18W_7.5x11.6mm_P1.27mm
U4: MCP2562-E-SN; SOIC-8_3.9x4.9mm_P1.27mm
U5: NCV8114BSN330T1G; TSOT-23-5
U6: MB85RQ8MX; SOIC-16W_7.5x10.3mm_P1.27mm
U8, U9: TC7S14F; TSOT-23-5_HandSoldering
Y1: 8MHz; Crystal_HC49-4H_Vertical

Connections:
+3.3V: C1.2, C3.1, C5.2, C10.1, R4.2, U2.8 (VCC), U3.18 (VDD), U4.5 (Vio), U5.5 (OUT)
+3V3: C12.2, C14.2, C18.1, R9.1, R24.2, R26.2, U1.12 (3V3), U6.1 (~HOLD(IO3)), U6.2 (VDD), U6.9 (~WP(IO2)), U8.5 (VCC), U9.5 (VCC)
+5V: C4.2, C9.1, PS1.3 (+VOUT), U1.14 (VBUS), U4.3 (VDD), U5.1 (IN), U5.3 (EN)
+12V: C15.1, C16.1, C17.1, D1.1 (K), D9.2 (A), J2.1, J2.2, Q4.2 (S), R11.1, R12.1
CAN_H: J2.7, J2.8, R6.2, U4.7 (CANH)
CAN_L: J2.5, J2.6, R6.1, U4.6 (CANL)
CAN_RX: U3.2 (RXCAN), U4.4 (RXD)
CAN_TX: U3.1 (TXCAN), U4.1 (TXD)
GND: C1.1, C3.2, C4.1, C5.1, C6.2, C7.2, C9.2, C10.2, C11.1, C12.1, C13.1, C14.1, C15.2, C16.2, C18.2, D1.2 (A), D3.1 (K), J1.1, J2.3, J2.4, J3.1, J3.3, PS1.2 (GND), Q3.2 (S), R14.2, U1.13 (GND), U2.5 (GND), U3.9 (VSS), U4.2 (VSS), U4.8 (STBY), U5.2 (GND), U6.10 (VSS), U8.3 (GND), U9.3 (GND)
unnamed: C11.2, R25.2, U8.2
unnamed: C13.2, R27.2, U9.2
unnamed: D3.2 (A), R11.2
unnamed: D9.1 (K), PS1.1 (+VIN)
unnamed: J1.2, Q2.2 (S)
unnamed: J3.2, R26.1, R27.1
unnamed: J3.4, R24.1, R25.1
unnamed: Q2.3 (D), Q4.3 (D)
unnamed: C17.2, Q2.1 (G), Q4.1 (G), R12.2, R13.1
unnamed: Q3.3 (D), R13.2
unnamed: Q3.1 (G), R10.2, R14.1
unnamed: R4.1, U3.17 (~RESET)
OSC1: C6.1, U3.8 (OSC1), Y1.2
OSC2: C7.1, U3.7 (OSC2), Y1.1
RS485_A: J1.3, R1.1, U2.6 (A)
RS485_B: J1.4, R1.2, U2.7 (B)
RS485_DI: U1.7 (GPIO0/TX), U2.4 (DI)
RS485_EN: U1.2 (GPIO27/ADC1/A1), U2.2 (~RE), U2.3 (DE)
RS485_RO: U1.8 (GPIO1/RX), U2.1 (RO)
SPI_CS_MCP2515: U1.1 (GPIO26/ADC0/A0), U3.16 (~CS)
SPI_MISO: U1.10 (GPIO4/MISO), U3.15 (SO), U6.8 (SO(IO1))
SPI_MOSI: U1.11 (GPIO3/MOSI), U3.14 (SI), U6.15 (SI(IO0))
SPI_SCK: U1.9 (GPIO2/SCK), U3.13 (SCK), U6.16 (SCK)
SPI_~CS_FeRAM0: R9.2, U1.3 (GPIO28/ADC2/A2), U6.7 (~CS)
ServoPower_EN: R10.1, U1.4 (GPIO29/ADC3/A3)
Umbilical_GseIgnition: U1.6 (GPIO7/SCL), U8.4
Umbilical_GseValve: U1.5 (GPIO6/SDA), U9.4

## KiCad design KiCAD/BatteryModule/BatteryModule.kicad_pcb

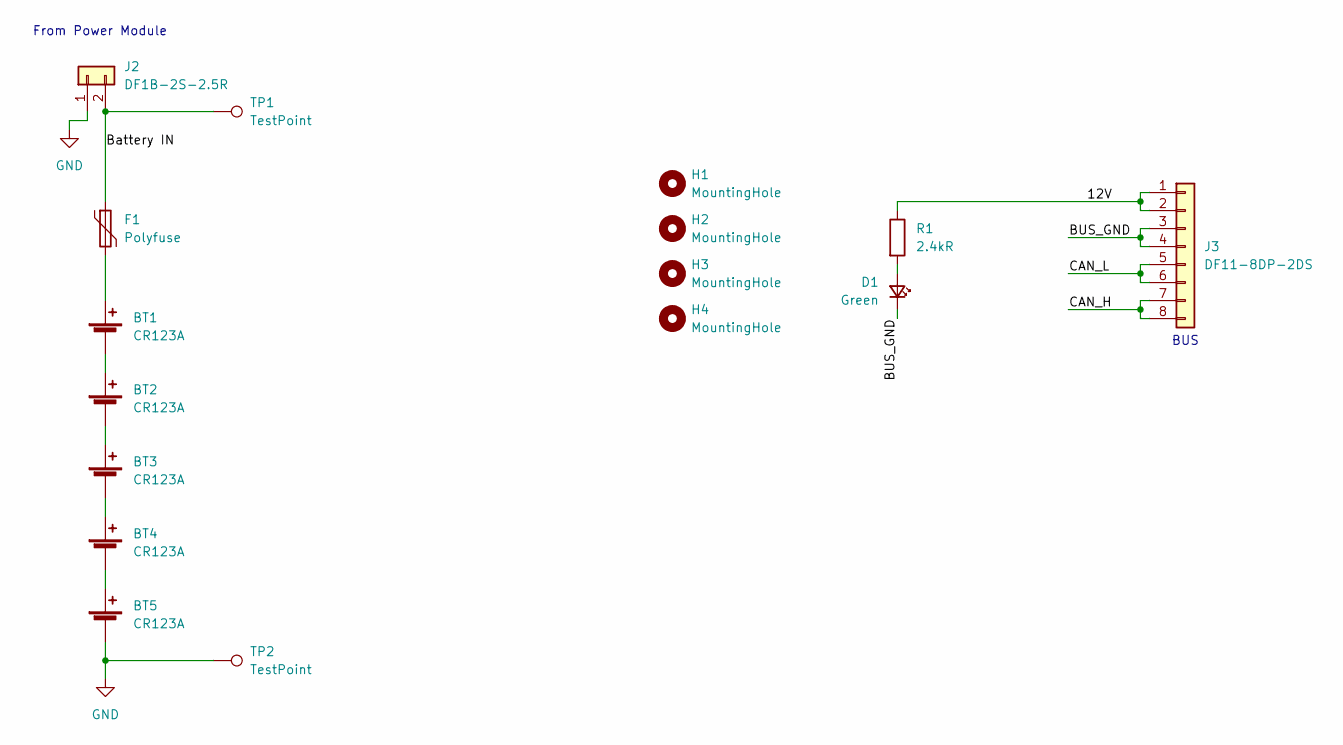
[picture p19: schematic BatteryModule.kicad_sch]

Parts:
BT1, BT2, BT3, BT4, BT5: CR123A; BHC-CR123A
D1: Green; LED_0603_1608Metric_Pad1.05x0.95mm_HandSolder
F1: Polyfuse; Fuse_Bourns_MF-RHT300
H1, H2, H3, H4: MountingHole; MountingHole_3.2mm_M3_Pad_TopBottom
J2: DF1B-2S-2.5R
J3: DF11-8DP-2DS
R1: 2.4kR; R_0603_1608Metric_Pad0.98x0.95mm_HandSolder
TP1, TP2: TestPoint; TestPoint_THTPad_D2.0mm_Drill1.0mm

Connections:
/12V: J3.1, J3.2, R1.1
/BUS_GND: D1.1 (K), J3.3, J3.4
/Battery IN: F1.1, J2.2, TP1.1
/CAN_H: J3.7, J3.8
/CAN_L: J3.5, J3.6
GND: BT5.2 (-), J2.1, TP2.1
unnamed: BT1.1 (+), F1.2
unnamed: BT1.2 (-), BT2.1 (+)
unnamed: BT2.2 (-), BT3.1 (+)
unnamed: BT3.2 (-), BT4.1 (+)
unnamed: BT4.2 (-), BT5.1 (+)
unnamed: D1.2 (A), R1.2

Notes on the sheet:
BUS
From Power Module

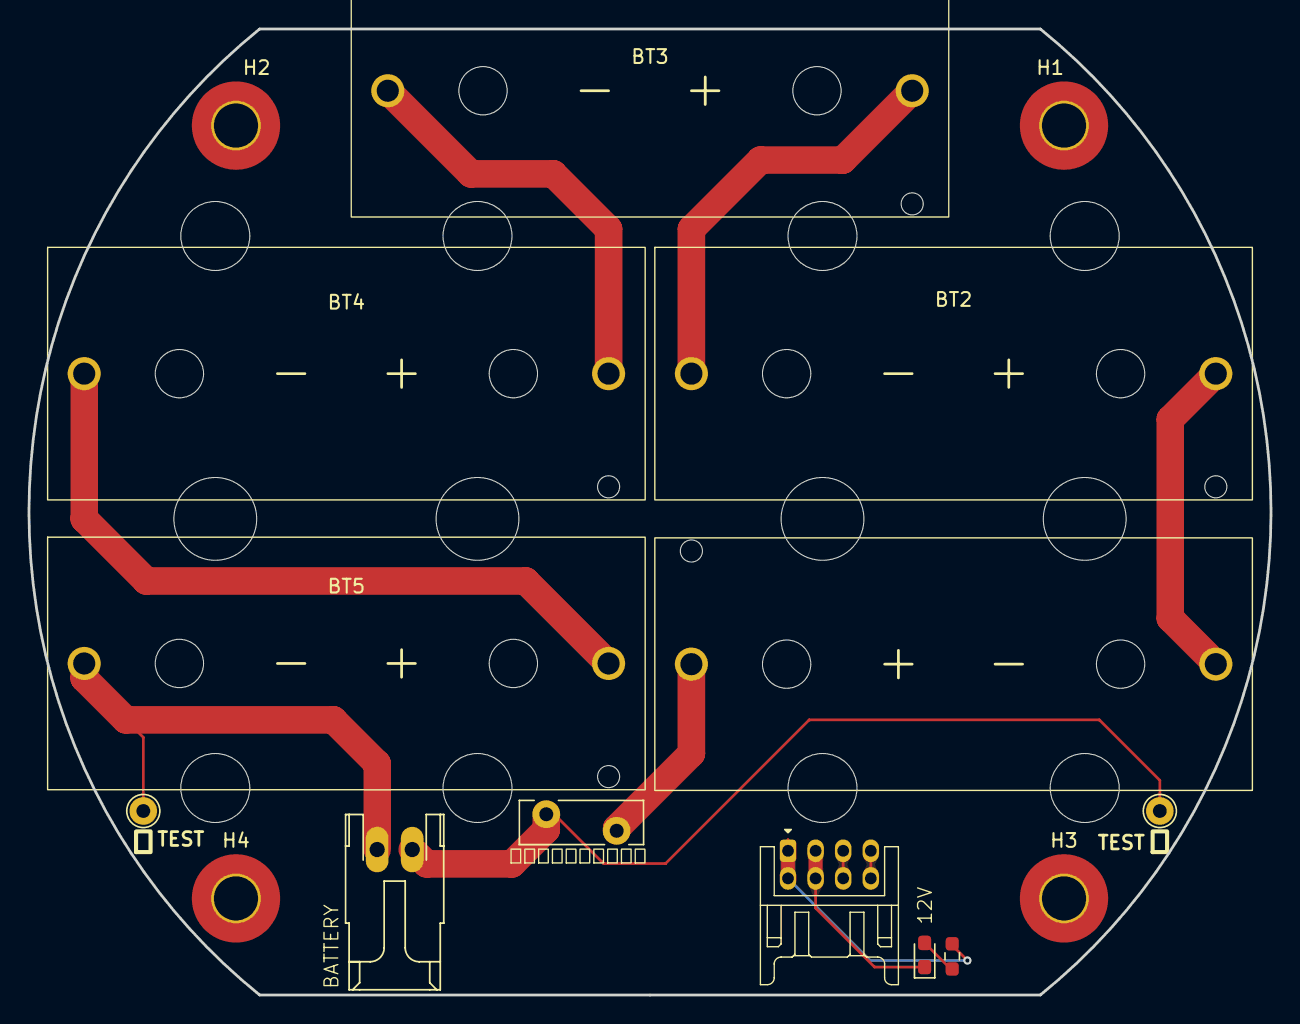
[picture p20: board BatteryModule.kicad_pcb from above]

Board: 2 copper layers, 90.0 x 70.0 mm, 16 parts (0 on the bottom side), 12 nets.

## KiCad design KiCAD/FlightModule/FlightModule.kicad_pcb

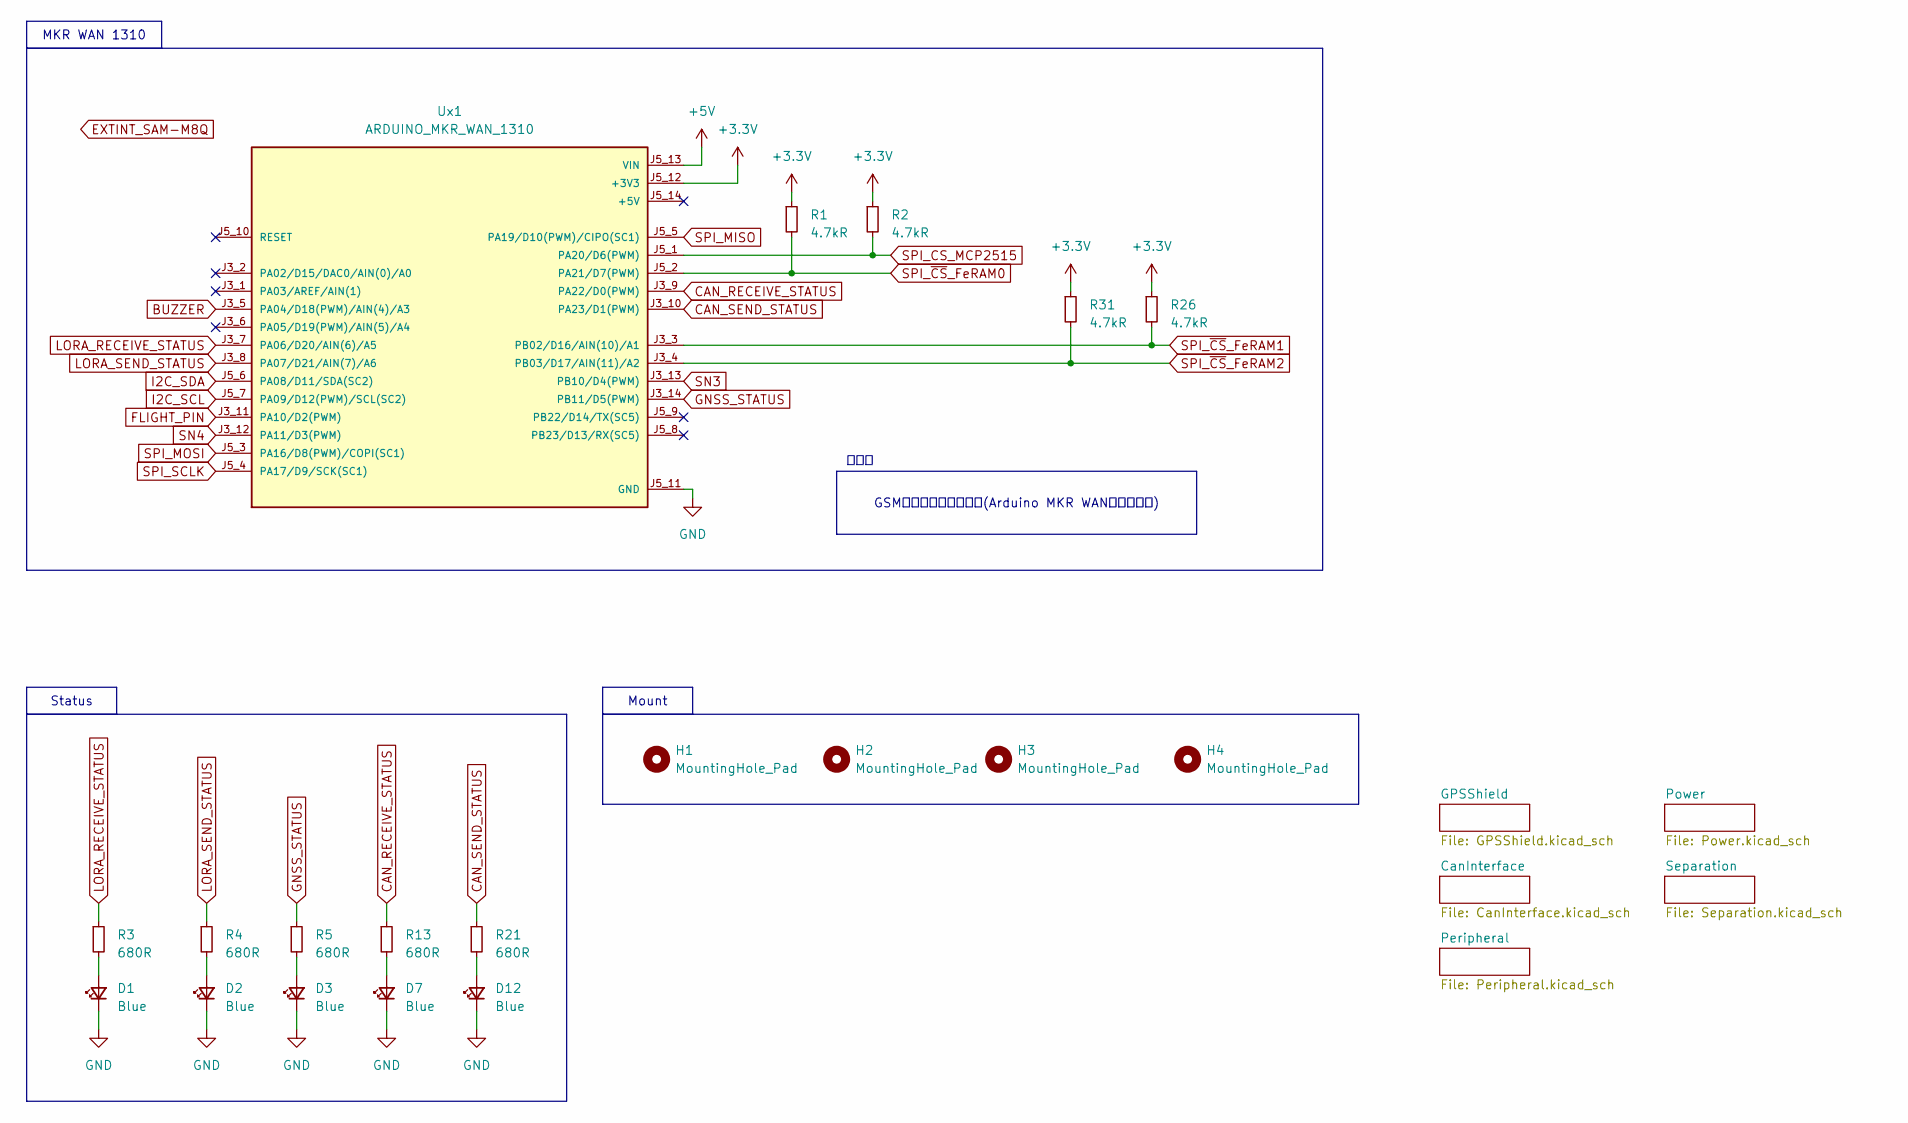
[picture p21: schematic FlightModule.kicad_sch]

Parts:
D1, D2, D3, D7, D12: Blue; LED_0603_1608Metric_Pad1.05x0.95mm_HandSolder
H1, H2, H3, H4: MountingHole_Pad; MountingHole_3.2mm_M3_Pad_TopBottom
R1, R2, R26, R31: 4.7kR; R_0603_1608Metric_Pad0.98x0.95mm_HandSolder
R3, R4, R5, R13, R21: 680R; R_0603_1608Metric_Pad0.98x0.95mm_HandSolder
Ux1: ARDUINO_MKR_WAN_1310; BOARD_ARDUINO_MKR_WAN_1310; PARTREV 06/27/2019

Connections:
+3.3V: R1.1, R2.1, R26.1, R31.1, Ux1.J5_12 (+3V3); also elsewhere on the board
+5V: Ux1.J5_13 (VIN); also elsewhere on the board
BUZZER: Ux1.J3_5 (PA04/D18(PWM)/AIN(4)/A3); also elsewhere on the board
CAN_RECEIVE_STATUS: R13.1, Ux1.J3_9 (PA22/D0(PWM))
CAN_SEND_STATUS: R21.1, Ux1.J3_10 (PA23/D1(PWM))
FLIGHT_PIN: Ux1.J3_11 (PA10/D2(PWM)); also elsewhere on the board
GND: D1.1 (K), D2.1 (K), D3.1 (K), D7.1 (K), D12.1 (K), Ux1.J5_11 (GND); also elsewhere on the board
GNSS_STATUS: R5.1, Ux1.J3_14 (PB11/D5(PWM))
I2C_SCL: Ux1.J5_7 (PA09/D12(PWM)/SCL(SC2)); also elsewhere on the board
I2C_SDA: Ux1.J5_6 (PA08/D11/SDA(SC2)); also elsewhere on the board
LORA_RECEIVE_STATUS: R3.1, Ux1.J3_7 (PA06/D20/AIN(6)/A5)
LORA_SEND_STATUS: R4.1, Ux1.J3_8 (PA07/D21/AIN(7)/A6)
unnamed: D1.2 (A), R3.2
unnamed: D2.2 (A), R4.2
unnamed: D3.2 (A), R5.2
unnamed: D7.2 (A), R13.2
unnamed: D12.2 (A), R21.2
SN3: Ux1.J3_13 (PB10/D4(PWM)); also elsewhere on the board
SN4: Ux1.J3_12 (PA11/D3(PWM)); also elsewhere on the board
SPI_CS_MCP2515: R2.2, Ux1.J5_1 (PA20/D6(PWM)); also elsewhere on the board
SPI_MISO: Ux1.J5_5 (PA19/D10(PWM)/CIPO(SC1)); also elsewhere on the board
SPI_MOSI: Ux1.J5_3 (PA16/D8(PWM)/COPI(SC1)); also elsewhere on the board
SPI_SCLK: Ux1.J5_4 (PA17/D9/SCK(SC1)); also elsewhere on the board
SPI_~CS_FeRAM0: R1.2, Ux1.J5_2 (PA21/D7(PWM)); also elsewhere on the board
SPI_~CS_FeRAM1: R26.2, Ux1.J3_3 (PB02/D16/AIN(10)/A1); also elsewhere on the board
SPI_~CS_FeRAM2: R31.2, Ux1.J3_4 (PB03/D17/AIN(11)/A2); also elsewhere on the board

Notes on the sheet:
付属品
GSMダイポールアンテナ(Arduino MKR WAN用アンテナ)
Mount
MKR WAN 1310
Status


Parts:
C1: 330uF; CP_Elec_10x10
C10, C11: 1uF; C_0805_2012Metric_Pad1.18x1.45mm_HandSolder
D4: Green; LED_0603_1608Metric_Pad1.05x0.95mm_HandSolder
D5: GS1010FL; D_SOD-123F
PS1: M78AR05-0.5; M78AR03305; Manufacturer_Part_Number M78AR05-0.5
R6: 2.4kR; R_0603_1608Metric_Pad0.98x0.95mm_HandSolder
U5: NCV8114BSN330T1G; TSOT-23-5

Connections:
+3.3V: C11.1, U5.5 (OUT); also elsewhere on the board
+5V: C10.1, PS1.3 (+VOUT), U5.1 (IN), U5.3 (EN); also elsewhere on the board
+12V: C1.1, D5.2 (A), R6.1; also elsewhere on the board
GND: C1.2, C10.2, C11.2, D4.1 (K), PS1.2 (GND), U5.2 (GND); also elsewhere on the board
unnamed: D4.2 (A), R6.2
unnamed: D5.1 (K), PS1.1 (+VIN)

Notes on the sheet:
本当は RT9080-33GJ5
Power Good
Linear Regulator
Switching Regulator
To MCU
From BUS
From DCDC


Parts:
C4, C5, C13: 0.1uF; C_0603_1608Metric_Pad1.08x0.95mm_HandSolder
C6, C7: 15pF; C_0603_1608Metric_Pad1.08x0.95mm_HandSolder
J1: DF11B-8DP-2DS; DF11-8DP-2DS
R11: 120R; R_0603_1608Metric_Pad0.98x0.95mm_HandSolder
R14: 10kR; R_0603_1608Metric_Pad0.98x0.95mm_HandSolder
U8: MCP2562-E-SN; SOIC-8_3.9x4.9mm_P1.27mm
U9: MCP2515-xST; TSSOP-20_4.4x6.5mm_P0.65mm
Y1: 8MHz; Crystal_SMD_HC49-SD

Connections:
+3.3V: C4.2, C5.2, R14.2, U8.5 (Vio), U9.20 (VDD); also elsewhere on the board
+5V: C13.2, U8.3 (VDD); also elsewhere on the board
+12V: J1.1, J1.2; also elsewhere on the board
CAN_H: J1.7, J1.8, R11.1, U8.7 (CANH)
CAN_L: J1.5, J1.6, R11.2, U8.6 (CANL)
CAN_RX: U8.4 (RXD), U9.2 (RXCAN)
CAN_TX: U8.1 (TXD), U9.1 (TXCAN)
GND: C4.1, C5.1, C6.2, C7.2, C13.1, J1.3, J1.4, U8.2 (VSS), U8.8 (STBY), U9.10 (VSS); also elsewhere on the board
unnamed: R14.1, U9.19 (~RESET)
OSC1: C6.1, U9.9 (OSC1), Y1.2
OSC2: C7.1, U9.8 (OSC2), Y1.1
SPI_CS_MCP2515: U9.18 (~CS); also elsewhere on the board
SPI_MISO: U9.17 (SO); also elsewhere on the board
SPI_MOSI: U9.16 (SI); also elsewhere on the board
SPI_SCLK: U9.14 (SCK); also elsewhere on the board

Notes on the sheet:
BUS：CAN + 電源ライン
組み立て位置により終端抵抗の 取り付けを有無を決めること
CANコントローラー
CANトランシーバー


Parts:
C16, C17: 1uF; C_0805_2012Metric_Pad1.18x1.45mm_HandSolder
R27: 100kR; R_0603_1608Metric_Pad0.98x0.95mm_HandSolder
R28: 0R; R_0603_1608Metric_Pad0.98x0.95mm_HandSolder
R29, R30: 4.7kR; R_0603_1608Metric_Pad0.98x0.95mm_HandSolder
U3: SAM-M8Q-0-10; MODULE_SAM-M8Q-0-10; PARTREV R07

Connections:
+3.3V: C16.1, C17.1, R27.1, R28.1, R29.1, R30.1, U3.2 (VCC_IO), U3.17 (VCC); also elsewhere on the board
EXTINT_SAM-M8Q: U3.19 (EXTINT0)
GND: C16.2, C17.2, U3.1 (GND), U3.4 (GND), U3.5 (GND), U3.6 (GND), U3.10 (GND), U3.11 (GND), U3.15 (GND), U3.16 (GND), U3.20 (GND); also elsewhere on the board
I2C_SCL: R29.2, U3.12 (SCL); also elsewhere on the board
I2C_SDA: R30.2, U3.9 (SDA); also elsewhere on the board
unnamed: R28.2, U3.3 (V_BCKP)
UART_RXD: R27.2, U3.14 (RXD)
UART_TXD: U3.13 (TXD)

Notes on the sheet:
ジャンパ抵抗
GNSS


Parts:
BZ1: UGCM1205XP; Buzzer_12x9.5RM7.6
C8, C9, C14, C15, C18: 0.1uF; C_0603_1608Metric_Pad1.08x0.95mm_HandSolder
J4: DF51-2P-2DS
Q3: 2SC3325-Y; SC-59_Handsoldering
R22: 4.7kR; R_0603_1608Metric_Pad0.98x0.95mm_HandSolder
R23, R24, R25: 10kR; R_0603_1608Metric_Pad0.98x0.95mm_HandSolder
U1, U2, U4: MB85RQ8MX; SOIC-16W_7.5x10.3mm_P1.27mm
U7: TC7S14F; TSOT-23-5_HandSoldering

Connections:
+3.3V: C9.2, C14.1, C15.1, C18.1, R24.2, U1.1 (~HOLD(IO3)), U1.2 (VDD), U1.9 (~WP(IO2)), U2.1 (~HOLD(IO3)), U2.2 (VDD), U2.9 (~WP(IO2)), U4.1 (~HOLD(IO3)), U4.2 (VDD), U4.9 (~WP(IO2)), U7.5 (VCC); also elsewhere on the board
+5V: BZ1.1 (-); also elsewhere on the board
BUZZER: R22.1; also elsewhere on the board
FLIGHT_PIN: U7.4; also elsewhere on the board
GND: C8.1, C9.1, C14.2, C15.2, C18.2, J4.1, Q3.2 (E), R23.1, U1.10 (VSS), U2.10 (VSS), U4.10 (VSS), U7.3 (GND); also elsewhere on the board
unnamed: BZ1.2 (+), Q3.3 (C)
unnamed: C8.2, R25.2, U7.2
unnamed: J4.2, R24.1, R25.1
unnamed: Q3.1 (B), R22.2, R23.2
SPI_MISO: U1.8 (SO(IO1)), U2.8 (SO(IO1)), U4.8 (SO(IO1)); also elsewhere on the board
SPI_MOSI: U1.15 (SI(IO0)), U2.15 (SI(IO0)), U4.15 (SI(IO0)); also elsewhere on the board
SPI_SCLK: U1.16 (SCK), U2.16 (SCK), U4.16 (SCK); also elsewhere on the board
SPI_~CS_FeRAM0: U1.7 (~CS); also elsewhere on the board
SPI_~CS_FeRAM1: U2.7 (~CS); also elsewhere on the board
SPI_~CS_FeRAM2: U4.7 (~CS); also elsewhere on the board

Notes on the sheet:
現在の状態を把握するため
FeRAM2
FeRAM0
FeRAM1
ブザー
フライトピン


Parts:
D8, D10: Green; LED_0603_1608Metric_Pad1.05x0.95mm_HandSolder
D9, D11: GS1010FL; D_SOD-123F
J5: DF51A-4P-2DSA
Q1, Q2: AO3400A; SOT-23
R15, R18: 300R; R_0603_1608Metric_Pad0.98x0.95mm_HandSolder
R16, R19: 10kR; R_0603_1608Metric_Pad0.98x0.95mm_HandSolder
R17, R20: 2.4kR; R_0603_1608Metric_Pad0.98x0.95mm_HandSolder

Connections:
+12V: D9.1 (K), D11.1 (K), J5.2, J5.4, R17.1, R20.1; also elsewhere on the board
GND: Q1.2 (S), Q2.2 (S), R16.1, R19.1; also elsewhere on the board
unnamed: D8.2 (A), R17.2
unnamed: D8.1 (K), D9.2 (A), J5.3, Q1.3 (D)
unnamed: D10.2 (A), R20.2
unnamed: D10.1 (K), D11.2 (A), J5.1, Q2.3 (D)
unnamed: Q1.1 (G), R15.2, R16.2
unnamed: Q2.1 (G), R18.2, R19.2
SN3: R15.1; also elsewhere on the board
SN4: R18.1; also elsewhere on the board

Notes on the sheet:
12V ラインをMOSFETにより駆動
SN4
SN3



Board: 2 copper layers, 90.0 x 70.0 mm, 74 parts (19 on the bottom side), 48 nets.

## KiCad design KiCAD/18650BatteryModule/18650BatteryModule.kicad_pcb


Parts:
BT1, BT2, BT3, BT4: 1042; BAT_1042; PARTREV E
D1: Green; LED_0603_1608Metric_Pad1.05x0.95mm_HandSolder
F1: Polyfuse; Fuse_Bourns_MF-RHT300
H1, H2, H3, H4: MountingHole; MountingHole_3.2mm_M3_Pad_TopBottom
J1: DF1B-2S-2.5R
J2: DF11-8DP-2DS
R1: 2.4kR; R_0603_1608Metric_Pad0.98x0.95mm_HandSolder
TP1: TestPoint; TestPoint_THTPad_D1.0mm_Drill0.5mm
TP2: TestPoint_GND; TestPoint_THTPad_1.0x1.0mm_Drill0.5mm

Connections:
/12V: J2.1, J2.2, R1.1
/BUS_GND: D1.1 (K), J2.3, J2.4
/CAN_H: J2.7, J2.8
/CAN_L: J2.5, J2.6
GND: BT4.N, J1.1, TP2.1
unnamed: BT1.N, BT2.P
unnamed: BT1.P, F1.2
unnamed: BT2.N, BT3.P
unnamed: BT3.N, BT4.P
unnamed: D1.2 (A), R1.2
unnamed: F1.1, J1.2, TP1.1

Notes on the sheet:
From Power Module
BUS



Board: 2 copper layers, 94.0 x 70.0 mm, 15 parts (2 on the bottom side), 11 nets.

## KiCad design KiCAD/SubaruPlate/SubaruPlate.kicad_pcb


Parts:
H1, H2, H3, H4: MountingHole; MountingHole_3.2mm_M3_Pad_TopBottom

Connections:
GND: H1.1, H2.1, H3.1, H4.1; also elsewhere on the board

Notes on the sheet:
M3 Mount


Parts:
C1, C14: 10uF; C_0603_1608Metric_Pad1.08x0.95mm_HandSolder
C2, C13: 0.1uF; C_0603_1608Metric_Pad1.08x0.95mm_HandSolder
J1: Wire_Soldering; PinHeader_1x04_P1.27mm_Vertical
R1, R2, R3, R14, R16: 10kR; R_0603_1608Metric_Pad0.98x0.95mm_HandSolder
U1, U6: LPS28DFW; CCLGA-7L

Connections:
+3.3V: C1.1, C2.1, C13.1, C14.1, J1.2, R2.1, R3.1, R14.1, R16.1, U1.6 (VDD), U6.2 (SA0), U6.6 (VDD)
GND: C1.2, C2.2, C13.2, C14.2, J1.1, R1.2, U1.5 (GND), U1.7 (LID), U6.5 (GND), U6.7 (LID); also elsewhere on the board
I2C_SCL: J1.4, R3.2, R16.2, U1.3 (SCL), U6.3 (SCL)
I2C_SDA: J1.3, R2.2, R14.2, U1.1 (SDA), U6.1 (SDA)
unnamed: R1.1, U1.2 (SA0)

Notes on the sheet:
I2C Address: 0x5D
I2C Address: 0x5C
データシート LPS28DFW
Adafruit LPS28
STマイクロ LPS28DFW
気圧センサー
I2C バス
参考資料

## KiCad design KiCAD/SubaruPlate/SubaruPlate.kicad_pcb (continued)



Board: 2 copper layers, 140.0 x 140.0 mm, 16 parts (2 on the bottom side), 5 nets.

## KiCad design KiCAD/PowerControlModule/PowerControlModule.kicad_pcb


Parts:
H1, H2, H3, H4: MountingHole; MountingHole_3.2mm_M3_Pad_TopBottom

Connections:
GND: H1.1, H2.1, H3.1, H4.1; also elsewhere on the board

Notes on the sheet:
マウント


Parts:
C13, C16, C17: 0.1uF; C_0603_1608Metric_Pad1.08x0.95mm_HandSolder
C14, C15: 15pF; C_0603_1608Metric_Pad1.08x0.95mm_HandSolder
C19, C20: 2.2uF; C_0603_1608Metric_Pad1.08x0.95mm_HandSolder
D3: Green; LED_0603_1608Metric_Pad1.05x0.95mm_HandSolder
D5: SMAJ45A; D_SMA
D10: SS2040FL; D_SOD-123F
J3: DF11-8DP-2DS
R21: 3.6kR; R_0603_1608Metric_Pad0.98x0.95mm_HandSolder
R24: 10kR; R_0603_1608Metric_Pad0.98x0.95mm_HandSolder
R25: 120R; R_0603_1608Metric_Pad0.98x0.95mm_HandSolder
U2: MCP2515-xST; TSSOP-20_4.4x6.5mm_P0.65mm
U8: MCP2562-E-SN; SOIC-8_3.9x4.9mm_P1.27mm
U9: MCP1792x-5002xCB; SOT-23_Handsoldering
Y1: 8MHz; Crystal_HC49-4H_Vertical

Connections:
+3.3V: C13.1, C16.2, R24.2, U2.20 (VDD), U8.5 (Vio); also elsewhere on the board
+5VD: C17.2, C20.1, D10.2 (A), U8.3 (VDD), U9.2 (VO)
+12V: C19.1, D5.1 (K), D10.1 (K), J3.1, J3.2, R21.1, U9.3 (VI); also elsewhere on the board
CAN_H: J3.7, J3.8, R25.2, U8.7 (CANH)
CAN_L: J3.5, J3.6, R25.1, U8.6 (CANL)
CAN_RX: U2.2 (RXCAN), U8.4 (RXD)
CAN_TX: U2.1 (TXCAN), U8.1 (TXD)
GND: C13.2, C14.2, C15.2, C16.1, C17.1, C19.2, C20.2, D3.1 (K), D5.2 (A), J3.3, J3.4, U2.10 (VSS), U8.2 (VSS), U8.8 (STBY), U9.1 (GND); also elsewhere on the board
unnamed: D3.2 (A), R21.2
unnamed: R24.1, U2.19 (~RESET)
OSC1: C14.1, U2.9 (OSC1), Y1.2
OSC2: C15.1, U2.8 (OSC2), Y1.1
SPI_CS_MCP2515: U2.18 (~CS); also elsewhere on the board
SPI_MISO: U2.17 (SO); also elsewhere on the board
SPI_MOSI: U2.16 (SI); also elsewhere on the board
SPI_SCK: U2.14 (SCK); also elsewhere on the board

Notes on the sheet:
終端抵抗．モジュールに応じて取り付ける．
CANトランシーバー
CAN バス
CANコントローラー


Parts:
C1: 220uF; CP_Radial_D6.3mm_P2.50mm
C2, C4: 22uF; C_0805_2012Metric_Pad1.18x1.45mm_HandSolder
C3, C5, C22: 0.1uF; C_0603_1608Metric_Pad1.08x0.95mm_HandSolder
C9: 2200uF; CP_Radial_D18.0mm_P7.50mm
C10: 0.1uF; C_0603_1608Metric
C11: 33uF; CP_Elec_6.3x5.9
C18, C21: 0.056uF; L_0603_1608Metric
D1, D2: Orange; LED_0603_1608Metric_Pad1.05x0.95mm_HandSolder
D4: SMAJ45A; D_SMA
D7, D8, D9: Red; LED_0603_1608Metric_Pad1.05x0.95mm_HandSolder
J1, J2: DF1B-2S-2.5R
Q1, Q2, Q4, Q5, Q7, Q9: AO3401A; SOT-23_Handsoldering
Q3: AO3400A; TSOT-23_HandSoldering
Q6, Q10: AO3401A; SOT-23; not fitted
Q11, Q12: Si4162DY; SOIC-8_3.9x4.9mm_P1.27mm
R3, R6, R7, R22, R26: 10kR; R_0603_1608Metric_Pad0.98x0.95mm_HandSolder
R4, R18, R19: 5.6kR; R_0603_1608Metric_Pad0.98x0.95mm_HandSolder
R5, R20: 3.3kR; R_0603_1608Metric_Pad0.98x0.95mm_HandSolder
R8: 4.7kR; R_0603_1608Metric_Pad0.98x0.95mm_HandSolder
R9, R13, R14: 680R; R_0603_1608Metric_Pad0.98x0.95mm_HandSolder
R10, R11, R12: 15mR; R_2512_6332Metric_Pad1.40x3.35mm_HandSolder
R15, R16: 2.7kR; R_0603_1608Metric_Pad0.98x0.95mm_HandSolder
R17: 820; R_0603_1608Metric_Pad0.98x0.95mm_HandSolder
R27: 10k; R_0603_1608Metric
TH1: Thermistor_NTC; PinHeader_1x02_P2.00mm_Vertical
U3, U4, U6: INA228; VSSOP-10_3x3mm_P0.5mm
U5: LTC4353; MSOP-16_3x4.039mm_P0.5mm
U11: LTC3119; StrawberryLinux_LTC3119

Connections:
+3.3V: C3.1, C5.1, C22.1, D7.2 (A), D8.2 (A), D9.2 (A), R26.1, R27.1, U3.6 (VS), U4.2 (A0), U4.6 (VS), U6.1 (A1), U6.2 (A0), U6.6 (VS); also elsewhere on the board
+12V: R12.2, U6.9 (Vin-); also elsewhere on the board
+VSW: Q7.2 (S), U11.12 (VIN), U11.13 (VIN), U11.14 (RUN)
/PowerControl/BATT: C2.1, J2.2, Q2.2 (S), R4.1
/PowerControl/BATT_LOWER: C21.2, Q12.1 (S), Q12.2 (S), Q12.3 (S), R11.1, U4.9 (Vin-), U5.4 (VIN2)
/PowerControl/BATT_UPPER: Q4.2 (S), R11.2, U4.8 (Vbus), U4.10 (Vin+)
/PowerControl/BUS_LOWER: C1.1, R12.1, U6.8 (Vbus), U6.10 (Vin+), U11.3 (VOUT), U11.4 (VOUT)
/PowerControl/GPU: C4.1, J1.2, Q5.2 (S), R7.1
/PowerControl/GPU_LOWER: C18.2, Q11.1 (S), Q11.2 (S), Q11.3 (S), R10.2, U3.9 (Vin-), U5.13 (VIN1)
/PowerControl/GPU_UPPER: Q9.2 (S), R10.1, U3.8 (Vbus), U3.10 (Vin+)
BATT_EN: R17.1; also elsewhere on the board
GND: C1.2, C3.2, C5.2, C9.2, C10.2, C22.2, J1.1, J2.1, Q3.2 (S), R3.2, R6.2, R8.2, R20.2, R22.2, TH1.2, U3.1 (A1), U3.2 (A0), U3.7 (GND), U4.1 (A1), U4.7 (GND), U5.15 (GND), U6.7 (GND), U11.1 (GND), U11.5 (GND), U11.6 (GND), U11.9 (GND), U11.10 (GND), U11.11 (GND), U11.16 (GND); also elsewhere on the board
I2C_SCL: U3.5 (SCL), U4.5 (SCL), U6.5 (SCL); also elsewhere on the board
I2C_SDA: U3.4 (SDA), U4.4 (SDA), U6.4 (SDA); also elsewhere on the board
LTC3119_PGOOD: R27.2, U11.2 (PGOOD); also elsewhere on the board
LTC4353_EN1: R3.1, U5.16 (EN1); also elsewhere on the board
LTC4353_EN2: R6.1, U5.1 (EN2); also elsewhere on the board
unnamed: D1.2 (A), R15.1
unnamed: D1.1 (K), U5.9 (ONST1)
unnamed: D2.2 (A), R16.1
unnamed: D2.1 (K), U5.8 (ONST1)
unnamed: C9.1, D4.2 (A), R18.1
unnamed: C11.1, D4.1 (K), Q1.2 (S), Q11.5 (D), Q11.6 (D), Q11.7 (D), Q11.8 (D), Q12.5 (D), Q12.6 (D), Q12.7 (D), Q12.8 (D), R15.2, R16.2, R18.2, R19.1, U5.7 (OUT2), U5.10 (OUT1)
unnamed: D7.1 (K), R9.1
unnamed: D8.1 (K), R13.1
unnamed: D9.1 (K), R14.1
unnamed: Q1.3 (D), Q7.3 (D)
unnamed: C11.2, Q1.1 (G), Q7.1 (G), R19.2, R20.1
unnamed: Q2.3 (D), Q4.3 (D)
unnamed: C2.2, Q2.1 (G), Q4.1 (G), R4.2, R5.1
unnamed: Q3.3 (D), R5.2
unnamed: Q3.1 (G), R17.2, R22.1
unnamed: Q5.3 (D), Q9.3 (D)
unnamed: C4.2, Q5.1 (G), Q9.1 (G), R7.2, R8.1
unnamed: Q11.4 (G), U5.12 (GATE1)
unnamed: Q12.4 (G), U5.5 (GATE2)
unnamed: R14.2, U3.3 (~Alert)
unnamed: R13.2, U4.3 (~Alert)
unnamed: C18.1, U5.11 (CPO1)
unnamed: C21.1, U5.6 (CPO2)
unnamed: C10.1, U5.14 (VCC)
unnamed: R9.2, U6.3 (~Alert)
unnamed: U11.7 (VCC), U11.8 (MPPC), U11.15 (PWM/SYNC)
VREF_T1: R26.2, TH1.1; also elsewhere on the board

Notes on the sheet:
SLAVE ADDRESS: 0b1000000
逆流防止ロードスイッチ
今までの接続 H-59 H-60
From Ground Power Unit [GPU] (External)
SLAVE ADDRESS: 0b100 0001
17V
15Vくらい
AO3401A
SLAVE ADDRESS: 100 0101
2:S
3:D
Pch MOSFET
From Battery Module (Internal)
1:G
R7, R8 で分圧して5.5Vくらい
0.015 ohm 1% 3W 電流検出抵抗
R4, R5 で分圧して5.5Vくらい
ソースとドレインのピン番号が反対で接続されていた


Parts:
D11: SS2040FL; D_SOD-123F
R1, R2, R23: 4.7kR; R_0603_1608Metric_Pad0.98x0.95mm_HandSolder
U1: XIAO-RP2040-DIP; XIAO-RP2040-SMD

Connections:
+3.3V: R1.1, R2.1, R23.1, U1.12 (3V3); also elsewhere on the board
+5V: D11.2 (A); also elsewhere on the board
BATT_EN: U1.7 (GPIO0/TX); also elsewhere on the board
GND: U1.13 (GND); also elsewhere on the board
I2C_SCL: R2.2, U1.6 (GPIO7/SCL); also elsewhere on the board
I2C_SDA: R1.2, U1.5 (GPIO6/SDA); also elsewhere on the board
LTC3119_PGOOD: U1.8 (GPIO1/RX); also elsewhere on the board
LTC4353_EN1: U1.3 (GPIO28/ADC2/A2); also elsewhere on the board
LTC4353_EN2: U1.4 (GPIO29/ADC3/A3); also elsewhere on the board
unnamed: D11.1 (K), U1.14 (VBUS)
SPI_CS_MCP2515: R23.2, U1.1 (GPIO26/ADC0/A0); also elsewhere on the board
SPI_MISO: U1.10 (GPIO4/MISO); also elsewhere on the board
SPI_MOSI: U1.11 (GPIO3/MOSI); also elsewhere on the board
SPI_SCK: U1.9 (GPIO2/SCK); also elsewhere on the board
VREF_T1: U1.2 (GPIO27/ADC1/A1); also elsewhere on the board


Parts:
D6: SS2040FL; D_SOD-123F
PS1: M78AR05-0.5; M78AR03305; Manufacturer_Part_Number M78AR05-0.5

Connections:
+5V: PS1.3 (+VOUT); also elsewhere on the board
+12V: D6.2 (A); also elsewhere on the board
GND: PS1.2 (GND); also elsewhere on the board
unnamed: D6.1 (K), PS1.1 (+VIN)

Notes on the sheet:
逆接続保護ダイオード
Switching Regulator
From BUS
To MCU


Board: 2 copper layers, 90.0 x 70.0 mm, 84 parts (1 on the bottom side), 60 nets.

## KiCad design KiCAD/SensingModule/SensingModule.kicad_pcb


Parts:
D1, D2: Blue; LED_0603_1608Metric_Pad1.05x0.95mm_HandSolder
H5, H6, H7, H8: MountingHole_Pad; MountingHole_3.2mm_M3_DIN965_Pad_TopBottom
J1: DF11-8DP-2DS
J2: MONITOR; DF11-8DP-2DS; not fitted
R1, R2: 680R; R_0603_1608Metric_Pad0.98x0.95mm_HandSolder
R5, R6, R7, R8, R9, R17: 4.7kR; R_0603_1608Metric_Pad0.98x0.95mm_HandSolder
U1: ARDUINO_MKR_WAN_1310; BOARD_ARDUINO_MKR_WAN_1310; PARTREV 06/27/2019

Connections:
+3.3V: J2.1, R5.2, R6.2, R7.2, R8.2, R17.2, U1.J5_12 (+3V3); also elsewhere on the board
+3.3VP: R9.2; also elsewhere on the board
+5V: U1.J5_13 (VIN); also elsewhere on the board
+12V: J1.1, J1.2; also elsewhere on the board
CAN_H: J1.7, J1.8; also elsewhere on the board
CAN_L: J1.5, J1.6; also elsewhere on the board
CAN_RECEIVE_STATUS: U1.J3_9 (PA22/D0(PWM)); also elsewhere on the board
CAN_SEND_STATUS: U1.J3_10 (PA23/D1(PWM)); also elsewhere on the board
GND: D1.1 (K), D2.1 (K), J1.3, J1.4, J2.2, U1.J5_11 (GND); also elsewhere on the board
I2C_SCL: J2.4, R8.1, U1.J5_7 (PA09/D12(PWM)/SCL(SC2)); also elsewhere on the board
I2C_SDA: J2.3, R7.1, U1.J5_6 (PA08/D11/SDA(SC2)); also elsewhere on the board
LORA_RECEIVE_STATUS: R1.1, U1.J3_13 (PB10/D4(PWM))
LORA_SEND_STATUS: R2.1, U1.J3_14 (PB11/D5(PWM))
unnamed: D1.2 (A), R1.2
unnamed: D2.2 (A), R2.2
SPI_CS_MCP: R9.1, U1.J5_2 (PA21/D7(PWM)); also elsewhere on the board
SPI_MISO: U1.J5_5 (PA19/D10(PWM)/CIPO(SC1)); also elsewhere on the board
SPI_MOSI: U1.J5_3 (PA16/D8(PWM)/COPI(SC1)); also elsewhere on the board
SPI_SCLK: U1.J5_4 (PA17/D9/SCK(SC1)); also elsewhere on the board
SPI_~CS_FeRAM0: R6.1, U1.J5_9 (PB22/D14/TX(SC5)); also elsewhere on the board
SPI_~CS_FeRAM1: R5.1, U1.J3_4 (PB03/D17/AIN(11)/A2); also elsewhere on the board
SPI_~CS_FeRAM2: R17.1, U1.J5_8 (PB23/D13/RX(SC5)); also elsewhere on the board
VREF_T1: J2.5, U1.J3_5 (PA04/D18(PWM)/AIN(4)/A3)
VREF_T2: J2.6, U1.J3_6 (PA05/D19(PWM)/AIN(5)/A4)
VREF_T3: J2.7, U1.J3_7 (PA06/D20/AIN(6)/A5)
VREF_T4: J2.8, U1.J3_8 (PA07/D21/AIN(7)/A6)
VREF_THERMISTOR: U1.J3_2 (PA02/D15/DAC0/AIN(0)/A0); also elsewhere on the board

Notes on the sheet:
LoRa Status
M3 MoutHole


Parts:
C4, C5, C6: 0.1uF; C_0603_1608Metric_Pad1.08x0.95mm_HandSolder
C7, C8: 15pF; C_0603_1608Metric_Pad1.08x0.95mm_HandSolder
D5, D6: Blue; LED_0603_1608Metric_Pad1.05x0.95mm_HandSolder
R11: 120R; R_0603_1608Metric_Pad0.98x0.95mm_HandSolder
R12, R13: 680R; R_0603_1608Metric_Pad0.98x0.95mm_HandSolder
R14: 10kR; R_0603_1608Metric_Pad0.98x0.95mm_HandSolder
U4: MCP2515-xST; TSSOP-20_4.4x6.5mm_P0.65mm
U9: MCP2562-E-SN; SOIC-8_3.9x4.9mm_P1.27mm
Y1: 8MHz; Crystal_HC49-4H_Vertical

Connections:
+3.3VP: C5.2, C6.2, R14.2, U4.20 (VDD), U9.5 (Vio); also elsewhere on the board
+5V: C4.2, U9.3 (VDD); also elsewhere on the board
CAN_H: R11.1, U9.7 (CANH); also elsewhere on the board
CAN_L: R11.2, U9.6 (CANL); also elsewhere on the board
CAN_RECEIVE_STATUS: R12.1; also elsewhere on the board
CAN_RX: U4.2 (RXCAN), U9.4 (RXD)
CAN_SEND_STATUS: R13.1; also elsewhere on the board
CAN_TX: U4.1 (TXCAN), U9.1 (TXD)
GND: C4.1, C5.1, C6.1, C7.2, C8.2, D5.1 (K), D6.1 (K), U4.10 (VSS), U9.2 (VSS), U9.8 (STBY); also elsewhere on the board
unnamed: D5.2 (A), R12.2
unnamed: D6.2 (A), R13.2
unnamed: R14.1, U4.19 (~RESET)
OSC1: C7.1, U4.9 (OSC1), Y1.2
OSC2: C8.1, U4.8 (OSC2), Y1.1
SPI_CS_MCP: U4.18 (~CS); also elsewhere on the board
SPI_MISO: U4.17 (SO); also elsewhere on the board
SPI_MOSI: U4.16 (SI); also elsewhere on the board
SPI_SCLK: U4.14 (SCK); also elsewhere on the board

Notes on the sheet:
CAN Status
CAN トランシーバー
CAN コントローラー

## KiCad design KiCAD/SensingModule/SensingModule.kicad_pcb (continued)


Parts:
C1: 330uF; CP_Elec_10x10
C10, C11: 1uF; C_0805_2012Metric_Pad1.18x1.45mm_HandSolder
D3: Green; LED_0603_1608Metric_Pad1.05x0.95mm_HandSolder
D7: SS2040FL; D_SOD-123F
PS1: M78AR05-0.5; M78AR03305; Manufacturer_Part_Number M78AR05-0.5
R10: 2.2kR; R_0603_1608Metric_Pad0.98x0.95mm_HandSolder
U8: RT9080-33GJ5; TSOT-23-5

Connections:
+3.3VP: C11.1, U8.5 (OUT); also elsewhere on the board
+5V: C10.1, PS1.3 (+VOUT), U8.1 (IN), U8.3 (EN); also elsewhere on the board
+12V: C1.1, D7.2 (A), R10.1; also elsewhere on the board
GND: C1.2, C10.2, C11.2, D3.1 (K), PS1.2 (GND), U8.2 (GND); also elsewhere on the board
unnamed: D3.2 (A), R10.2
unnamed: D7.1 (K), PS1.1 (+VIN)

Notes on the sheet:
本当は RT9080-33GJ5
逆接続保護ダイオード
12V Status
From BUS
To MCU
Switching Regulator
Linear Regulator
From DCDC


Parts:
C14, C15, C16: 0.1uF; C_0603_1608Metric_Pad1.08x0.95mm_HandSolder
J3: DF51-2P-2DS
J4: DF51A-4P-2DS
R15: 10kR; R_0603_1608Metric_Pad0.98x0.95mm_HandSolder
U2: BNO055; AE-BNO055-BO
U5, U6, U7: MB85RQ8MX; SOIC-16W_7.5x10.3mm_P1.27mm
U14: SOIC-16W_7.5x10.3mm_P1.27mm; not fitted

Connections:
+3.3V: C14.1, C15.1, C16.1, J4.2, R15.1, U2.1 (VIN), U5.1 (~HOLD(IO3)), U5.2 (VDD), U5.9 (~WP(IO2)), U6.1 (~HOLD(IO3)), U6.2 (VDD), U6.9 (~WP(IO2)), U7.1 (~HOLD(IO3)), U7.2 (VDD), U7.9 (~WP(IO2)), U14.8 (WP(IO2)), U14.9 (HOLD(IO3)), U14.10 (VDD); also elsewhere on the board
GND: C14.2, C15.2, C16.2, J3.1, J4.1, U2.2 (GND), U2.7 (GND), U5.10 (VSS), U6.10 (VSS), U7.10 (VSS), U14.7 (VSS); also elsewhere on the board
I2C_SCL: J4.4, U2.4 (SCL/R); also elsewhere on the board
I2C_SDA: J4.3, U2.3 (SDA/T); also elsewhere on the board
SPI_MISO: U5.8 (SO(IO1)), U6.8 (SO(IO1)), U7.8 (SO(IO1)), U14.16 (SO(IO1)); also elsewhere on the board
SPI_MOSI: U5.15 (SI(IO0)), U6.15 (SI(IO0)), U7.15 (SI(IO0)), U14.2 (SI(IO0)); also elsewhere on the board
SPI_SCLK: U5.16 (SCK), U6.16 (SCK), U7.16 (SCK), U14.1 (SCK); also elsewhere on the board
SPI_~CS_FeRAM0: U5.7 (~CS); also elsewhere on the board
SPI_~CS_FeRAM1: U6.7 (~CS); also elsewhere on the board
SPI_~CS_FeRAM2: U7.7 (~CS); also elsewhere on the board
VREF_THERMISTOR: J3.2, R15.2; also elsewhere on the board

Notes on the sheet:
THERMISTOR
LPS28DFW
FeRAM1
BNO055
FeRAM2
FeRAM0
Thermistor



Board: 2 copper layers, 90.0 x 70.0 mm, 48 parts (23 on the bottom side), 32 nets.

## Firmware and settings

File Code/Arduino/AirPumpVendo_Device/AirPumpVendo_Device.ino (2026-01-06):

/*
 * Project: AirPumpVendo
 * File: AirPumpVendo_Device.ino
 * Description: Main firmware for the Air Pump Vending Machine.
 *              Handles communication with the desktop app, controls the air pump,
 *              and reads sensors (pressure, coin selector, etc.).
 * 
 * Author: 
 * Date: 2025-12-05
 * 
 * Board: Arduino Uno / Nano / ESP32 (Check configuration)
 */

const byte COIN_PIN = 2;                    // Must be interrupt-capable on Uno/Nano
const unsigned long COIN_TIMEOUT_MS = 200;  // Gap to consider "end of coin" (tweak if needed)

volatile unsigned int pulseCount = 0;  // Updated inside ISR
volatile unsigned long lastPulseTime = 0;

long totalCredit = 0;  // e.g. in pesos or credits

const String PREFIX_PAYMENT = "PAYMENT:";
const String PREFIX_INFLATE = "INFLATE:";
String inputBuffer = "";

int Payable = 0;         // This will hold the parsed amount
int TargetPressure = 0;  // Target pressure in PSI
#define LEDpin 13
bool Vending = false;


#define SolenoidPin 3
const int PRESSURE_PIN = A0;  // Analog pin where sensor signal is connected

// ADC / voltage configuration
const float VREF = 5.0;        // ADC reference voltage (5 V for typical Arduino)
const float ADC_MAX = 1023.0;  // 10-bit ADC max value

// Sensor characteristics (typical for 0.5–4.5 V transducer)
const float SENSOR_MIN_V = 0.5;    // Voltage at 0 MPa
const float SENSOR_MAX_V = 4.5;    // Voltage at full scale (1.2 MPa)
const float SENSOR_MAX_MPA = 1.2;  // Full-scale pressure in MPa

// Reading configuration
const unsigned long READ_INTERVAL_MS = 500;  // how often to print
const int NUM_SAMPLES = 10;                  // samples to average per reading

unsigned long lastReadTime = 0;
bool Inflating = false;
float pressureBar = 0.0;
float pressurePSI = 0.0;
int pressurePSI_Int = 0;

void coinPulseISR() {
  pulseCount++;
  lastPulseTime = millis();
}

void setup() {
  Serial.begin(115200);

  pinMode(LEDpin, OUTPUT);
  digitalWrite(LEDpin, 0);

  pinMode(SolenoidPin, OUTPUT);
  digitalWrite(SolenoidPin, 0);

  pinMode(COIN_PIN, INPUT_PULLUP);  // Expect active-LOW pulses
  pinMode(PRESSURE_PIN, INPUT);

  attachInterrupt(digitalPinToInterrupt(COIN_PIN), coinPulseISR, FALLING);

  Serial.println("AirPumpVendo Started...2");
}

void loop() {
  static unsigned long lastCheck = 0;
  unsigned long now = millis();

  if (pulseCount > 0) {
    // Copy volatile values atomically
    noInterrupts();
    unsigned int pulses = pulseCount;
    unsigned long lastPulse = lastPulseTime;
    interrupts();

    if (now - lastPulse > COIN_TIMEOUT_MS) {
      // No more pulses for a while -> treat as a finished coin
      noInterrupts();
      pulseCount = 0;  // reset for next coin
      interrupts();

      int coinValue = pulses;

      //   Serial.print("Detected ");
      //   Serial.print(pulses);
      //   Serial.print(" pulse(s) -> ");

      if (coinValue > 0) {
        totalCredit += coinValue;
        // Serial.print("Coin value: ");
        // Serial.print(coinValue);
        // Serial.print(" | Total credit: ");
        // Serial.println(totalCredit);
      } else {
        // Serial.println("Unknown coin / invalid pulse count");
      }

      //   Serial.println();
    }
  }

  SerialCOM();

  if (Vending) {
    digitalWrite(LEDpin, 1);
    delay(100);
    digitalWrite(LEDpin, 0);
    delay(100);
    Serial.println("INSERTED:" + String(totalCredit));
    if (Payable > 0) {
      if (totalCredit >= Payable) {
        Serial.println("PAYMENT COMPLETE");
        Vending = false;
        totalCredit = 0;
      }
    }
  }

  if (Inflating) {
    InflateTire();
  }
}

void InflateTire() {
  int offset=23;
  while (1) {
    digitalWrite(SolenoidPin, 1);
    if (TargetPressure > 20) {
      while (pressurePSI_Int < (TargetPressure + offset)) {
        ReadPressureInflate();
        pressurePSI_Int = (int)(pressurePSI);
        Serial.println("PRESSURE:" + String((pressurePSI_Int - offset)));
      }
    } else {
      delay(600);
    }
    digitalWrite(SolenoidPin, 0);

    delay(1500);

    ReadPressureInflate();

    pressurePSI_Int = (int)(pressurePSI);

    if (pressurePSI_Int >= TargetPressure) {
      Inflating = false;
      digitalWrite(SolenoidPin, 0);
      break;
    }
  }
}

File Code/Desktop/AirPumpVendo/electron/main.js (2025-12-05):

// File: electron/main.js
// Purpose: Electron main; maximized window, robust SerialPort IPC (cross-platform), CRLF writes,
//          line-based reads broadcast to renderer, and no-op reopen if same port.

const { app, BrowserWindow, ipcMain } = require("electron");
const path = require("path");
const { SerialPort } = require("serialport");

const isDev = process.env.NODE_ENV !== "production";
const DEV_URL = process.env.DEV_SERVER_URL || "http://localhost:3000";

// Show on-screen keyboard on touch devices
app.commandLine.appendSwitch("enable-virtual-keyboard");

let win;

// ---- Serial state & helpers ----
let serial = null;
let serialPath = null;
let serialBaud = null;
let readBuffer = ""; // accumulate bytes until newline

// Common USB-serial vendor IDs: Arduino, CH340, CP210x, FTDI
const ARDUINO_VIDS = new Set(["2341", "2a03", "1a86", "10c4", "0403"]);

async function listSerialPorts() {
  try {
    return await SerialPort.list();
  } catch (e) {
    console.warn("[serial] list failed:", e.message);
    return [];
  }
}

function guessPort(ports) {
  // Prefer known Arduino-like VIDs, else first port
  const byVid = ports.find((p) => ARDUINO_VIDS.has((p.vendorId || "").toLowerCase()));
  return (byVid || ports[0] || null)?.path || null;
}

function attachReadHandlers() {
  if (!serial) return;
  readBuffer = "";
  serial.on("data", (chunk) => {
    try {
      readBuffer += Buffer.isBuffer(chunk) ? chunk.toString("utf8") : String(chunk);
      // Emit each full line (handles \n or \r\n)
      let idx;
      while ((idx = readBuffer.indexOf("\n")) >= 0) {
        let line = readBuffer.slice(0, idx);
        if (line.endsWith("\r")) line = line.slice(0, -1);
        readBuffer = readBuffer.slice(idx + 1);
        if (win && !win.isDestroyed()) {
          win.webContents.send("serial:data", line);
        }
      }
    } catch (e) {
      console.warn("[serial] read error:", e.message);
    }
  });
}

async function openSerial(portPath, baud = 115200) {
  if (!portPath) throw new Error("No port path specified");

  // If already open with the same port/baud, keep it
  if (serial && serial.isOpen && serialPath === portPath && serialBaud === baud) {
    return { path: serialPath, baud: serialBaud };
  }

  // Close previous if different
  if (serial && serial.isOpen) {
    await new Promise((res) => serial.close(() => res()));
    serial = null;
  }

  return new Promise((resolve, reject) => {
    serial = new SerialPort({ path: portPath, baudRate: baud }, (err) => {
      if (err) return reject(err);
      serialPath = portPath;
      serialBaud = baud;
      console.log(`[serial] opened ${portPath} @ ${baud}`);
      serial.on("error", (e) => console.error("[serial] error:", e));
      serial.on("close", () => console.log("[serial] closed"));
      attachReadHandlers();
      resolve({ path: portPath, baud });
    });
  });
}

function writeSerial(line) {
  return new Promise((resolve, reject) => {
    if (!serial || !serial.isOpen) return reject(new Error("Serial not open"));
    // Append CRLF and wait for drain to ensure delivery
    const data = line.endsWith("\n") ? line : line + "\r\n";
    serial.write(data, "utf8", (err) => {
      if (err) return reject(err);
      serial.drain((err2) => (err2 ? reject(err2) : resolve(true)));
    });
  });
}

// ---- IPC exposed to renderer ----
ipcMain.handle("serial:list", async () => await listSerialPorts());
ipcMain.handle("serial:open", async (_e, portPath, baud) => {
  try {
    return await openSerial(portPath, baud || 115200);
  } catch (e) {
    throw new Error(e.message || String(e));
  }
});
ipcMain.handle("serial:write", async (_e, data) => await writeSerial(String(data)));
ipcMain.handle("serial:close", async () => {
  if (serial && serial.isOpen) await new Promise((res) => serial.close(() => res()));
  serial = null;
  serialPath = null;
  serialBaud = null;
  return true;
});
ipcMain.handle("serial:status", async () => ({
  isOpen: Boolean(serial && serial.isOpen),
  path: serialPath,
  baud: serialBaud,
}));

// Platform-aware auto-open (kiosk-friendly)
async function autoOpenSerial() {
  const platform = process.platform;

  if (platform === "linux") {
    for (const p of ["/dev/ttyUSB0", "/dev/ttyACM0"]) {
      try {
        await openSerial(p, 115200);
        return;
      } catch {}
      try {
        await openSerial(p, 9600);
        return;
      } catch {}
    }
  }

  // Fallback: enumerate and guess
  const ports = await listSerialPorts();
  const portPath = guessPort(ports);
  if (!portPath) {
    console.warn("[serial] no ports found to auto-open");
    return;
  }
  try {
    await openSerial(portPath, 115200);
  } catch (e1) {
    console.warn(`[serial] 115200 failed on ${portPath}:`, e1.message);
    try {
      await openSerial(portPath, 9600);
    } catch (e2) {
      console.warn(`[serial] 9600 failed on ${portPath}:`, e2.message);
    }
  }
}

// ---- Window bootstrap ----
function createWindow() {
  win = new BrowserWindow({
    fullscreen: false,
    kiosk: false,
    alwaysOnTop: false,
    autoHideMenuBar: true,
    backgroundColor: "#0b0f12",
    show: false,
    webPreferences: {
      preload: path.join(__dirname, "preload.js"),
      contextIsolation: true,
      nodeIntegration: false,
      sandbox: true,
    },
  });

  win.once("ready-to-show", () => {
    win.maximize();
    win.show();
  });

  if (isDev) {
    win.loadURL(DEV_URL);
  } else {
    win.loadFile(path.join(__dirname, "../ui/out/index.html"));
  }
}

// Fullscreen controls (unchanged)
ipcMain.handle("fullscreen:enter", () => win && win.setFullScreen(true));
ipcMain.handle("fullscreen:exit", () => win && win.setFullScreen(false));
ipcMain.handle("fullscreen:toggle", () => win && win.setFullScreen(!win.isFullScreen()));

app.whenReady().then(async () => {
  createWindow();
  await autoOpenSerial();
  app.on("activate", () => {
    if (BrowserWindow.getAllWindows().length === 0) createWindow();
  });
});

app.on("window-all-closed", () => {
  if (process.platform !== "darwin") app.quit();
});

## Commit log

2025-08-05 added files for the schematic/wiring diagram of the system (by parts)
    [VendoAirPump.fzz]
2025-08-10 added KiCAD files for the full schematic diagram of the project (as one)
    [AirPumpVendo.kicad_pcb, AirPumpVendo.kicad_sch, VendoAirPump.fzz]
2025-09-08 added initial code for the ESP32-CYD
2025-09-12 added codes for TireCodeAndInflation Screen
2025-10-30 added electron config[error when running npm run dev on electron]
    [main.js]
2025-10-31 Landing: switch all icons to Material Symbols (Rounded), remove emojis/SVGs, use Tailwind-only styling, and change CTA to START
2025-10-31 ui: Tailwind-only + Material Symbols; START→/select-service; add stubs; set static export; clean ui/package.json
2025-10-31 feat(tire): integrate tire-code whitelist + PSI table with validation; fix(next): await searchParams in /service/tire/result
2025-10-31 feat(inflation): add Tire Inflation Service UI (Payment→Connect→Inflate) with target PSI from result; wire navigation from results page
2025-10-31 feat(dot): add DOT Code Safety Check screen with instructions and next-step stub; wire navigation from services/results
2025-10-31 fixed on-screen keyboard for RPi-FullScreen
    [main.js]
2025-12-05 feat: Implement initial air pump vending machine desktop application with inflation service UI and embedded hardware examples.
2025-12-05 feat: Add tire inflation service UI with Electron serial communication for embedded payment processing, and an example Arduino sketch.
2025-12-05 feat: Implement initial Electron app with serial communication for air pump vending machine UI and embedded example.
2025-12-05 feat: Implement initial device setup, serial communication for payment, and coin input processing for the Air Pump Vending Machine.
2025-12-05 feat: Implement initial air pump vending system with embedded payment processing and desktop UI serial control.
2025-12-05 feat: implemented START inflation communication to Arduino, TODO: implement actual inflation using pressure sensor and solenoid valve
2025-12-05 feat: Introduce air pump vending machine firmware for payment, inflation, and serial communication, with a new inflation service UI.
2025-12-06 adjusted visuals during tire inflation to fit to RPi Screen
2025-12-07 fixed device algorithm on inflation
    [AirPumpVendo_Device.ino]
2025-12-07 feat: add tire PSI recommendation result page
2025-12-07 feat: Implement DOT code safety check results and tire inflation service with payment and live progress.
2026-01-06 fix: Adjust tire inflation logic to include pressure offset and improve serial output
    [AirPumpVendo_Device.ino]
2026-01-25 feat: Add tire service page allowing PSI lookup by tire code or manual input.
2026-01-25 feat: Implement DOT code safety check service, tire service result page, and settings context for managing application configurations.
2026-01-25 docs: Revise README to outline the new Electron/Next.js UI and Arduino firmware architecture, detail updated services like free DOT checks and manual PSI input, and refine hardware, installation, usa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
2026-01-28 Improves DOT code safety check and input method
    Refactors the DOT code input screen to use a numeric keypad
    for easier data entry. Also, enhances the safety check logic
    to consider the tire's manufacturing year and provides more
    specific guidance based on its age. Improves user feedback
    with clearer status messages and explanations.
2026-02-01 Improves DOT code input UI
    Enhances the user interface for DOT code input by adjusting sizes, spacing, and overall layout for a better user experience.
    This includes:
    - Reduced padding and margins
    - Adjusted font sizes
    - Modified button dimensions
    - Improved responsiveness
2026-02-10 updated schematics
    [AirPumpVendo_V2.kicad_pcb, AirPumpVendo_V2.kicad_sch, VendoAirPump.fzz]
2026-02-10 Adjusts total price calculation for manual inflation
    Updates the total price calculation to only include the inflation price when the manual inflation option is selected.
    This prevents double-charging the user when using the manual inflation feature.
